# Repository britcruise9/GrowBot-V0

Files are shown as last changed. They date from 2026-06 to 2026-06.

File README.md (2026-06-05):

# GrowBot V0

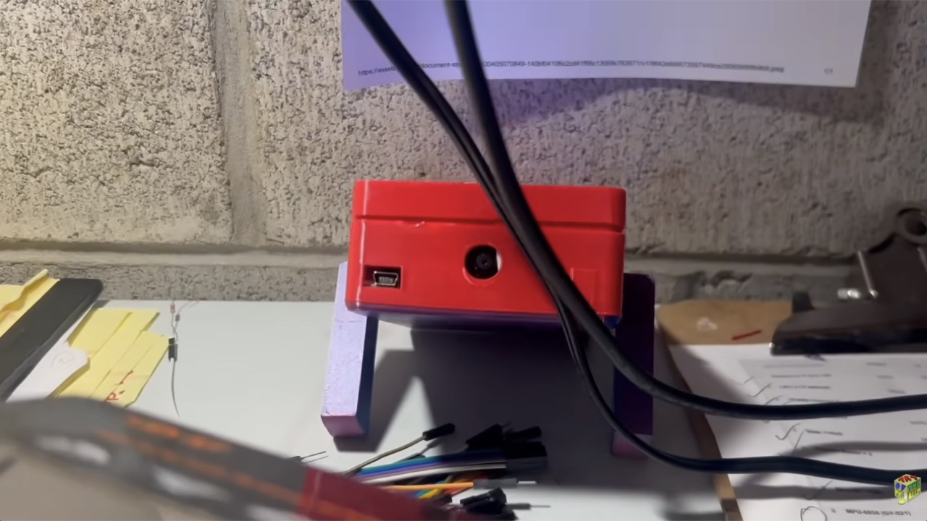
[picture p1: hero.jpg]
GrowBot V0 (https://www.youtube.com/watch?v=S67z2aekBrI)


▶ **[Watch the build video](https://www.youtube.com/watch?v=S67z2aekBrI)**

This project started when I imagined making a little robot that would learn everything, how to move and do things. A pure machine learning approach, using basic evolutionary algorithms and then a neural network. It then evolved to ask, "what if you gave a modern AI foundation model a nervous and motor system?" GrowBot collides these questions into a "general learning robot", which can be anything... and learns to move, see, and react from scratch.

Most importantly, getting physical AI in your hands: fast, easy, and cheap. So this project is the "simplest viable product": if you take a modern humanoid and delete everything down to the bare minimum, how cheap can you make it?

> [!WARNING]
> This is a V0 snapshot for research purposes, and it is still hacky (the servos and the Pi share a power rail, protected by a capacitor) because it is a work in progress. It is a reference for the build in the video, not a step by step guide for beginners, so expect to fill in some gaps. V1 is coming Fall 2026 as a more stable, tested platform with step by step build, testing, and training instructions, a custom PCBA, a calibrated digital twin, and a top secret thing I can't even show yet.

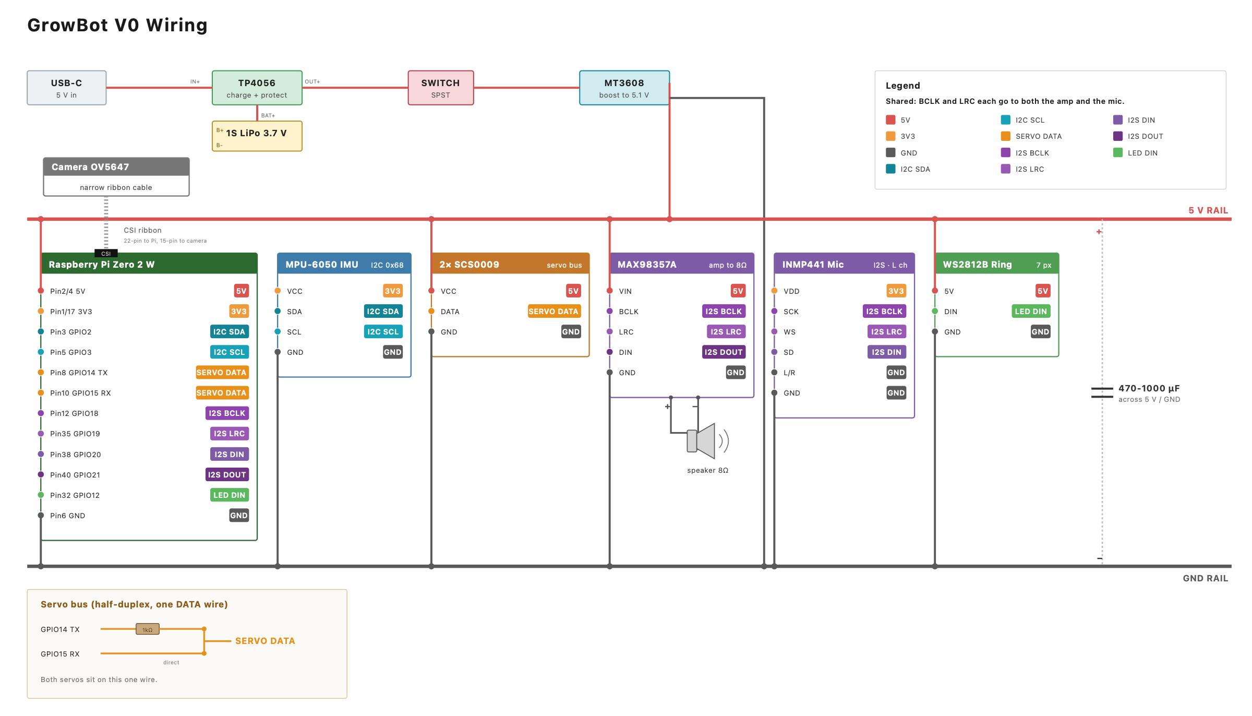
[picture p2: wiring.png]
GrowBot wiring diagram


## What's in here
- **[BOM.md](BOM.md)** is the full parts list with specs, rough prices, where I got things, the GPIO pin map, and the setup notes that gave me trouble.
- **[wiring.svg](wiring.svg)** is the full wiring diagram. The image above is the same thing.
- **[mechanical/stl_snapshot](mechanical/stl_snapshot)** is the current V0 body STL snapshot: holey top shell, matching base, and short rounded legs.
- **[simulation](simulation)** has a standalone MuJoCo body XML snapshot. The training setup is not included.

## The build at a glance
| Part of the robot | What I used |
|---|---|
| Brain | Raspberry Pi Zero 2 W (quad core, WiFi) and a microSD card |
| Legs | 2x Feetech SCS0009 serial bus servos (they report position and load) |
| Senses | OV5647 camera, MPU-6050 IMU, INMP441 mic |
| Voice and lights | MAX98357A amp into a small speaker, WS2812B LED ring |
| Power | one 1S LiPo into an MT3608 boost to 5 V, with a capacitor on the 5 V rail |

Everything runs on the Pi. There is no external computer.

## Software

Test policies are coming next, rolled out gradually as I verify each one on the robot.

The complete software is still in development. To get the hardware up and running, start with the basic setup and calibration software in **[`setup/`](setup/)**. Here is the big picture of what the hardware is built to support.

### LLM Integration (V0)
An onboard agent loop is the brain. It gathers the live sensor picture (camera, IMU, mic, servo feedback) and sends it to an LLM through an API. The model picks a goal and proposes an action, the robot tries it, and the result feeds back in. The WIP experimental runtime explores letting the LLM call the learned motor policies and sketch its own motions, with fast reflexes underneath as a safety floor.

### Learned Locomotion Policies
The low level motion comes from small motor policies that output bounded servo targets, not a hand written gait. I train them offline from short rollouts, then deploy compact versions onto the Pi. The robot logs its episodes, failures, and sensor traces so each run feeds the next training pass.

The training code, agent harness, reward functions, and trained policies are still under active development.

## License
[CC BY-NC 4.0](LICENSE): build it, modify it, and share it for non-commercial use, with credit to Art of the Problem.

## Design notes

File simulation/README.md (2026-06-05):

# GrowBot V0 Simulation Snapshot

`growbot_current_body.xml` is a standalone MuJoCo body snapshot for the current live GrowBot body.

The full setup is coming with the next version. For now it captures the measured body proportions and the rounded/rockered foot approximation I use for policy experiments. The agent harness, policy runtime, reward functions, and training code come with it.

The geometry is a measured box approximation of the same body the `mechanical/` STLs print
(body about 132 x 83 x 39 mm, 64 mm legs, the v215 rounded/rockered foot). It is close to the
printed shells within a few mm, not an exact mesh import, so print from the STLs and simulate
from this XML.

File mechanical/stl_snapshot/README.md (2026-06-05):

# GrowBot V0 STL Snapshot

This folder is a snapshot of the current V0 body geometry, shared as reference STL files. This is a work in progress and evolving at the moment, so expect the fit to keep changing.

| File | Notes |
|---|---|
| `growbot_v0_top_shell_holey.stl` | Top lid, fully perforated with vent holes, no text. Caps over the base. |
| `growbot_v0_base_shell.stl` | Base tray with corner mounting posts and side ports. Same footprint as the lid, so the top seats flush. |
| `growbot_v0_legs_64mm_rounded.stl` | Short 64 mm leg with a curved (rounded) foot. |

The body went through several revisions while I was building, so the holes and cutouts might not line up perfectly with the boards. The two holes in the middle of the body are for the IMU. I mounted things with 3M double sided squares instead of screws, which made small mismatches easy to work around.

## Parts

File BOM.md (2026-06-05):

# GrowBot V0 Bill of Materials

This is everything on the robot in the video. It is the single cell, breadboard friendly build, not the V1 PCB (that is a separate board I am still working on). If you want to copy what is in the video, this is the list.

The whole thing comes in well under $100.

## Parts

| # | Part | Spec | Qty | ~CAD | Where / notes |
|---|---|---|----:|----:|---|
| **Compute** |
| 1 | Raspberry Pi Zero 2 W | quad core A53, WiFi/BT, 40 pin | 1 | $22 | you will need to solder on a 40 pin header |
| 2 | microSD card | 16 to 32 GB, Class 10 / A1 | 1 | $8 | I run Raspberry Pi OS Lite (64 bit) |
| 3 | 2x20 GPIO header | 0.1 inch male | 1 | $1 | skip if your Pi already has one |
| **Actuation** |
| 4 | Feetech SCS0009 serial servo | half duplex UART 1 Mbps, 9 g, 1.5 kg·cm, 4 to 6 V (run ~5.1 V), 300° (same as Waveshare SC09) | 2 | $5 to 6 ea | I bought mine in bulk on AliExpress |
| 5 | 1 kΩ resistor | ¼ W | 1 | pennies | for the servo half duplex line |
| **Sensing** |
| 6 | MPU-6050 IMU (GY-521) | I²C 0x68, 6 axis, 3.3 V | 1 | $3 | |
| 7 | OV5647 camera (Pi Zero) | 5 MP, narrow 22 to 15 pin CSI ribbon | 1 | $12 | get the Pi Zero version with the narrow ribbon, not the standard one |
| 8 | INMP441 I²S mic | 3.3 V, 24 bit | 1 | $4 | |
| **Voice and lights** |
| 9 | MAX98357A I²S amp | 3.2 W class D mono | 1 | $5 | |
| 10 | speaker | 8 Ω, 0.5 to 3 W, small | 1 | $2 | |
| 11 | WS2812B LED ring | 7 pixels, 5 V | 1 | $3 | |
| **Power** |
| 12 | 1S LiPo or 18650 cell | 3.7 V, 800 to 1200 mAh | 1 | $4 | whatever you have on hand |
| 13 | TP4056 module | USB-C, charge and protect | 1 | $1 | get the protected version with OUT+/OUT- |
| 14 | MT3608 boost module | step up, set to about 5.1 V | 1 | pennies | |
| 15 | electrolytic cap | 470 to 1000 µF, 10 V or higher | 1 | pennies | goes across the 5 V rail at the servos |
| 16 | SPST power switch | | 1 | pennies | |
| | | | | **~$77 CAD** | about $56 USD |

## Also needed (not electronics)

- **3D printed body.** The STLs are in [`mechanical/`](mechanical/stl_snapshot/). Print in PLA or PETG, a small amount, well under a spool.
- **Hookup wire and dupont jumpers** to wire it up per the diagram.
- **Mounting.** I skipped screws and just stuck the boards down with 3M double sided mounting squares. Fast, and easy to move things around.

## GPIO pin map (Pi Zero 2 W, 40 pin header)

| Pi pin | Signal | Goes to |
|---:|---|---|
| 2 / 4 | 5 V | 5 V rail from the MT3608 (Pi, servos, amp, LED) |
| 1 | 3.3 V | IMU VCC |
| 17 | 3.3 V | mic VDD |
| 6 / 9 / 14 / 25 | GND | common ground rail |
| 3 | GPIO2 / SDA | IMU SDA |
| 5 | GPIO3 / SCL | IMU SCL |
| 8 | GPIO14 / TXD | 1 kΩ, then the servo DATA bus |
| 10 | GPIO15 / RXD | servo DATA bus (direct) |
| 12 | GPIO18 | amp BCLK and mic SCK (shared) |
| 35 | GPIO19 | amp LRC and mic WS (shared) |
| 38 | GPIO20 | mic SD (data in) |
| 40 | GPIO21 | amp DIN (data out) |
| 32 | GPIO12 | WS2812 DIN |
| CSI | ribbon | camera (not GPIO) |

## Power

> [!CAUTION]
> V0 runs the servos and the Pi off one shared 5 V rail. A capacitor across the rail covers the voltage dips when the servos pull hard. This is the hacky part of V0; V1 separates them properly.

The 3.3 V for the IMU and the mic comes from the Pi's own 3.3 V pins, not from the booster.

## Setup notes (the stuff that gave me trouble)

1. Set the MT3608 to about 5.1 V with a multimeter before you connect the Pi. These boost modules ship turned up high.
2. The servos talk over the Pi's serial port, but the Pi uses it for other things by default. To hand it to the servos: add `dtoverlay=disable-bt` to `/boot/config.txt` (this frees the good serial port from Bluetooth), and in `raspi-config` turn the serial login off but leave the serial port itself on. After that the servos are on `/dev/serial0`.
3. The SCS0009 use big endian byte order for the 2 byte reads and writes. I assumed little endian at first and it silently read and wrote garbage.
4. Assign servo IDs 1 and 2 (both ship as ID 1, so you need to change one). This was a headache at first. The 3-pin servo lead is GND, VCC (5 V), DATA, but check your own servo's pinout before plugging in.
5. Torque limit the servos to about 70 percent so a double stall stays inside the MT3608's 2 A budget, otherwise use dedicated power for full load (a second MT3608 on the same ground).
6. Mic L/R to GND gives the left channel. The amp SD pin has to be high to play sound, so tie it to 3.3 V, and leaving the amp GAIN pin floating is about 9 dB.
7. The Pi Zero needs the narrow CSI ribbon (22 pin to 15 pin), not the standard camera ribbon.
8. The WS2812 data line needs root, so launch with `sudo`.

## Power budget

| Draw | Typical | Peak |
|---|---:|-----:|
| Pi Zero 2 W | 200 mA | 400 mA |
| 2x SCS0009 (walking) | 400 mA | 1700 mA (both stalling) |
| Audio and LEDs | ~100 mA | ~400 mA |
| **Total** | **~700 mA** | **~2.1 A** |

The MT3608 is rated around 2 A, so normal walking is fine. A double stall goes over budget, which is why I torque limit the servos and added a capacitor to cover the dips.

Battery life is roughly 50 to 60 minutes of active play on an 800 to 1200 mAh cell.

## Software

The setup and calibration software is in [`setup/`](setup/). The learning agent and training code are still in development (V1).

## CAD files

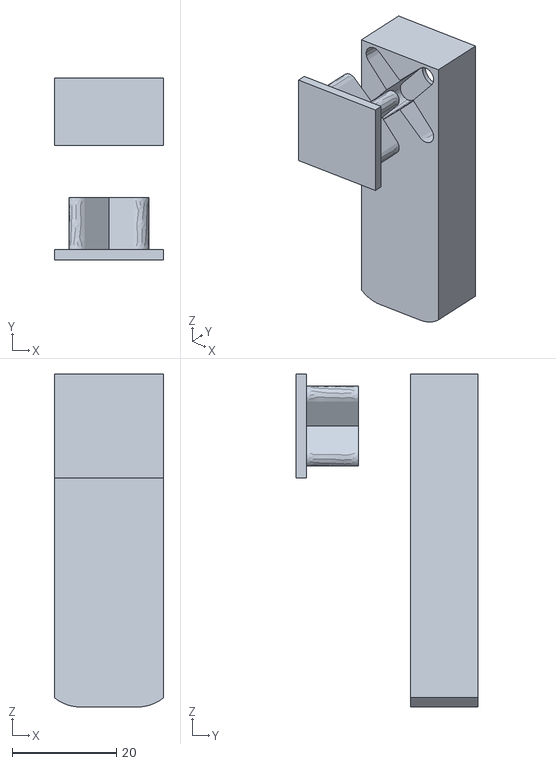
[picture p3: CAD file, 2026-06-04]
mechanical/stl_snapshot/growbot_v0_legs_64mm_rounded.stl
21.0 x 35.0 x 64.0

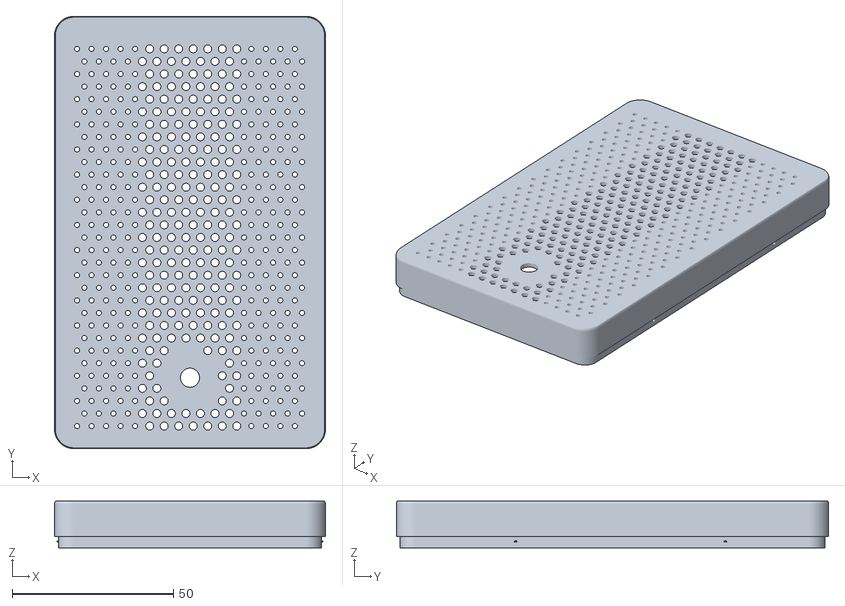
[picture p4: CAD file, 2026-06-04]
mechanical/stl_snapshot/growbot_v0_top_shell_holey.stl
84.0 x 134.0 x 14.5

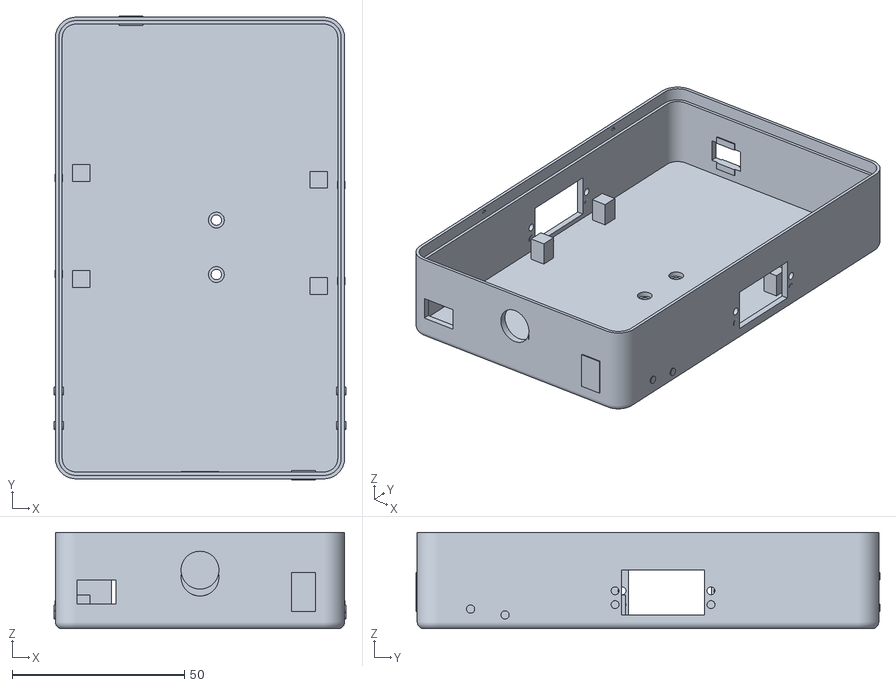
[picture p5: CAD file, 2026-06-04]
mechanical/stl_snapshot/growbot_v0_base_shell.stl
84.7 x 134.7 x 28.0

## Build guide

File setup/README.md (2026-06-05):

# GrowBot V0 Setup and Calibration Software

This is the basic software to bring the GrowBot hardware to life. It is a small driver package plus one quick test per subsystem (servos, LED ring, speaker, mic, IMU, camera), and a `hello_growbot.py` that runs lights, voice, and legs together. Its job is to prove the body works. It does not include the learning agent, the LLM brain, or the training code. Those are V1, still in development.

> [!IMPORTANT]
> The SCS0009 / SC09 servos store 2-byte values big-endian, for reads and writes. If you get nonsense positions or a servo that will not move past some point, check the byte order first. Little-endian code (Dynamixel style) looks like it works, then silently writes garbage. That one fact cost me a full day, so the driver here gets it right.

## What's in it

Drivers in `growbot/` (you import these):

| Module | What it does |
|---|---|
| `pins.py` | every wiring constant in one place (port, servo IDs, GPIO pins, encoder range). **Edit this to match your build.** |
| `servos.py` | SCS0009 servos, big-endian correct: scan, read position, move, sync-move |
| `leds.py` | WS2812 ring on GPIO12: fill, spin, off |
| `audio.py` | `speak(text)` through espeak-ng/flite and aplay; sample the mic level |
| `imu.py` | MPU-6050 over I2C: WHO_AM_I, accel, gyro |
| `camera.py` | capture one still from the Pi camera |

Scripts in `scripts/` (you run these):

| Command | What it does |
|---|---|
| `python3 scripts/scan_servos.py` | read-only: finds servos, prints positions, no motion |
| `python3 scripts/test_servos_safe.py` | nudges each leg a few degrees and back, then goes limp |
| `sudo python3 scripts/test_leds.py` | ring through red, green, blue, white, then a spin |
| `python3 scripts/test_audio.py` | says "hello, I'm GrowBot", then samples the mic |
| `python3 scripts/test_imu.py` | prints WHO_AM_I and live accel/gyro, tilt it to watch |
| `python3 scripts/test_camera.py` | captures one photo to /tmp |
| `sudo -E python3 scripts/hello_growbot.py` | the full hello: lights, voice, legs. Skips whatever is not present. |

## Setup

```bash
pip install -r requirements.txt
sudo apt install espeak-ng   # text-to-speech (flite also works)
# picamera2 and alsa-utils (aplay/arecord) ship with Raspberry Pi OS
```

The LED ring uses the Pi's PWM/DMA for WS2812 timing, which needs root, so run the LED test and the full hello with `sudo`.

## Quickstart

```bash
python3 scripts/scan_servos.py            # confirm the servo bus (read-only)
python3 scripts/test_servos_safe.py       # gentle leg nudge (hold the robot or use a stand)
sudo python3 scripts/test_leds.py         # ring colors and a spin
python3 scripts/test_audio.py             # speaker says hello, mic level
python3 scripts/test_imu.py               # tilt to watch accel/gyro
python3 scripts/test_camera.py            # one photo to /tmp
sudo -E python3 scripts/hello_growbot.py  # lights, voice, legs together
```

If `scan_servos.py` can't open the port: on a Pi Zero 2W the servo bus is `/dev/serial0` (the real PL011 UART), not `/dev/ttyS0` (which throws an Input/output error). Enable it with `raspi-config` > Interface Options > Serial Port: login shell off, serial hardware on, then reboot.

## SCS0009 register cheat sheet

All 2-byte values are big-endian.

| Reg | Name | Bytes | Notes |
|-----|---|---|---|
| 0x03 | ID | 1 | 1 to 253 |
| 0x28 | torque enable | 1 | 0 = limp, 1 = holding |
| 0x2A | goal position | 2 BE | 0 to 1023 |
| 0x30 | EEPROM lock | 1 | write 0 to unlock before changing 0x00 to 0x2F, 1 to lock |
| 0x38 | present position | 2 BE | read-only |

Packet: `FF FF <id> <len> <inst> <params...> <checksum>`, where `len = len(params) + 2` and `checksum = ~(id + len + inst + sum(params)) & 0xFF`. The bus is half-duplex, so every send is echoed back before the reply; strip the echo before parsing. The driver does this and checks the checksum so a stray echo byte can't be read as a position.

The SCS0009 reports 0 to 1023 across about 300 degrees. On my units the usable floor is 255, so the driver clamps motion to 255 to 1023.

## Tested on

A Raspberry Pi Zero 2W (Raspberry Pi OS Bookworm, 64-bit) with two SCS0009 servos on the PL011 UART at 1 Mbaud, an MPU-6050 IMU at I2C 0x68, a 7-pixel WS2812 ring on GPIO12, a MAX98357A amp into a speaker, an INMP441 mic, and a Pi camera. Your build will differ, so `growbot/pins.py` is where you reconcile it.

Audio note: the MAX98357A is usually set up with the googlevoicehat-soundcard overlay, so its ALSA card shows up as `sndrpigooglevoi` (that is the default in `pins.py`; change it if yours differs). If a play returns cleanly but you hear nothing, it is almost always speaker wiring, not software.

## Safety

These scripts move a real robot. `test_servos_safe.py` and `hello_growbot.py` move each joint a few degrees around where it currently is, so keep GrowBot on a stand or hold it, and keep fingers clear. Motion is clamped in software to the usable encoder range, and torque is released on exit, even on Ctrl-C. The scripts talk to servos by ID and make no left/right assumption, so you can bring up the bus before you have settled your own leg mapping.

## License

[CC BY-NC 4.0](../LICENSE), the same as the rest of the repo. Build it, change it, and share it for non-commercial use, with credit to Art of the Problem.

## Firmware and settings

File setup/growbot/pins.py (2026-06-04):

"""Bus, encoder, and register constants for the GrowBot bringup kit.

These describe how GrowBot's hardware is wired and its safe operating limits.
Edit them to match YOUR build.
"""

# --- Servo bus (SCS0009 / SC09 Feetech serial-bus servos) ---
# On a Raspberry Pi Zero 2W this is the real PL011 UART. NOT /dev/ttyS0, which
# exists but raises termios.error (5, 'Input/output error').
SERVO_PORT = "/dev/serial0"
SERVO_BAUD = 1_000_000

# Servo IDs present on the bus. GrowBot has two legs.
SERVO_IDS = (1, 2)

# Usable encoder range. The SCS0009 reports 0-1023 over its ~300 deg of travel,
# but the usable floor on our units is 255 - commanding below that just stalls
# at 255. Motion is clamped to this range so you can't drive into the dead zone.
ENCODER_MIN = 255
ENCODER_MAX = 1023

# Conservative nudge size (encoder units) for the safe-motion smoke tests.
# ~30 units is a few degrees: visible, gentle, nowhere near the end stops.
SAFE_NUDGE = 30

# --- SCS0009 register map (all 2-byte values are BIG-ENDIAN) ---
REG_ID = 0x03             # 1 byte, 1-253 (changing IDs is intentionally not in V0)
REG_TORQUE_ENABLE = 0x28  # 1 byte: 0 = off (limp), 1 = on (holding)
REG_GOAL_POS = 0x2A       # 2 bytes BE, 0-1023
REG_EEPROM_LOCK = 0x30    # 1 byte: write 0 to unlock, 1 to lock
REG_PRESENT_POS = 0x38    # 2 bytes BE, read-only

# --- IMU (MPU-6050 family) over I2C ---
IMU_I2C_ADDR = 0x68

# --- LED ring (WS2812 / NeoPixel) - needs root (PWM/DMA) ---
LED_PIN = 12          # GPIO12 = PWM0
LED_COUNT = 7
LED_BRIGHTNESS = 128  # 0-255
LED_FREQ_HZ = 800_000
LED_DMA = 10
LED_CHANNEL = 0       # PWM0 -> channel 0 (GPIO12/18); use 1 for GPIO13/19

# --- Audio (MAX98357A amp + INMP441 mic) ---
# ALSA device. The MAX98357A is usually set up with the googlevoicehat-soundcard
# overlay, so the card shows up as 'sndrpigooglevoi'. If yours differs, change this;
# audio.py also falls back to the default device if this one is not found.
AUDIO_DEVICE = "plughw:CARD=sndrpigooglevoi"
HELLO_PHRASE = "hello, I'm GrowBot"

# --- Body mapping ---
# NOTE: which servo ID drives which leg depends on YOUR horn mounting, so this
# kit never assumes a side - it tests servos by ID and nudges around each
# joint's current position. Record your own mapping here once you've confirmed
# it, e.g. LEFT_LEG_ID = 2 / RIGHT_LEG_ID = 1.

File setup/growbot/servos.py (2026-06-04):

"""Minimal big-endian-correct driver for SCS0009 / SC09 serial-bus servos.

The one fact that costs everyone a day: the SCS0009 stores 2-byte values
BIG-ENDIAN, for BOTH reads and writes. Dynamixel-style little-endian code
appears to work but silently writes garbage that the servo clips to its max
angle - which looks like a servo that refuses to move past some point.

Tested against SCS0009 servos on a Raspberry Pi Zero 2W over the raw UART
(no vendor SDK). Run scripts/scan_servos.py first to confirm the bus before
commanding any motion.
"""
from __future__ import annotations

import time

try:
    import serial  # pyserial
except ImportError:  # pragma: no cover - dependency hint
    serial = None

from .pins import (
    ENCODER_MAX,
    ENCODER_MIN,
    REG_GOAL_POS,
    REG_PRESENT_POS,
    REG_TORQUE_ENABLE,
    SERVO_BAUD,
    SERVO_PORT,
)

# Instruction codes
PING = 0x01
READ = 0x02
WRITE = 0x03
SYNC_WRITE = 0x83
BROADCAST_ID = 0xFE


def _checksum(sid: int, length: int, inst: int, params: list[int]) -> int:
    return (~(sid + length + inst + sum(params))) & 0xFF


def _packet(sid: int, inst: int, params: list[int]) -> bytes:
    length = len(params) + 2
    return bytes([0xFF, 0xFF, sid, length, inst] + list(params) + [_checksum(sid, length, inst, params)])


def _find_response(buf: bytes, sid: int) -> bytes | None:
    """Locate a checksum-valid response packet for ``sid`` inside ``buf``.

    Robust to the half-duplex echo and UART timing jitter: it scans for a
    well-formed ``FF FF <sid> ...`` frame whose checksum validates, rather than
    trusting byte offsets.
    """
    i = 0
    while i < len(buf) - 5:
        if buf[i] == 0xFF and buf[i + 1] == 0xFF and buf[i + 2] == sid:
            ln = buf[i + 3]
            end = i + 4 + ln
            if end <= len(buf):
                body = buf[i + 2 : end]
                if body[-1] == ((~sum(body[:-1])) & 0xFF):
                    return buf[i:end]
        i += 1
    return None


class ServoBus:
    """A thin, big-endian-correct interface to the SCS0009 servo bus."""

    def __init__(self, port: str = SERVO_PORT, baud: int = SERVO_BAUD, timeout: float = 0.05) -> None:
        if serial is None:
            raise RuntimeError("pyserial is not installed - run: pip install pyserial")
        self.ser = serial.Serial(port, baud, timeout=timeout)

    def close(self) -> None:
        try:
            self.ser.close()
        except Exception:
            pass

    def __enter__(self) -> "ServoBus":
        return self

    def __exit__(self, *exc) -> None:
        self.close()

    # --- low level -------------------------------------------------------
    def _txrx(self, sid: int, inst: int, params: list[int], read_extra: int = 16) -> bytes | None:
        pkt = _packet(sid, inst, params)
        self.ser.reset_input_buffer()
        self.ser.write(pkt)
        self.ser.flush()
        time.sleep(0.004)
        buf = self.ser.read(len(pkt) + read_extra)
        # Search after the TX echo so the echoed packet isn't read as a reply.
        idx = buf.find(pkt)
        start = idx + len(pkt) if idx >= 0 else 0
        return _find_response(buf[start:], sid)

    def ping(self, sid: int) -> bool:
        return self._txrx(sid, PING, [], read_extra=6) is not None

    def read_bytes(self, sid: int, reg: int, size: int) -> list[int] | None:
        resp = self._txrx(sid, READ, [reg, size], read_extra=size + 6)
        if not resp or len(resp) < 5 + size:
            return None
        return list(resp[5 : 5 + size])

    def read_word(self, sid: int, reg: int) -> int | None:
        data = self.read_bytes(sid, reg, 2)
        if not data:
            return None
        return (data[0] << 8) | data[1]  # BIG-ENDIAN

    def read_byte(self, sid: int, reg: int) -> int | None:
        data = self.read_bytes(sid, reg, 1)
        return data[0] if data else None

    def write_bytes(self, sid: int, reg: int, data: list[int]) -> None:
        self._txrx(sid, WRITE, [reg] + list(data), read_extra=6)

    def write_word(self, sid: int, reg: int, val: int) -> None:
        val = int(val) & 0xFFFF
        self.write_bytes(sid, reg, [(val >> 8) & 0xFF, val & 0xFF])  # BIG-ENDIAN

    def write_byte(self, sid: int, reg: int, val: int) -> None:
        self.write_bytes(sid, reg, [int(val) & 0xFF])

    # --- semantic helpers ------------------------------------------------
    def present_position(self, sid: int) -> int | None:
        """Read the servo's current encoder position (0-1023), or None."""
        return self.read_word(sid, REG_PRESENT_POS)

    def set_torque(self, sid: int, on: bool) -> None:
        """Enable (hold) or disable (go limp) the servo's torque."""
        self.write_byte(sid, REG_TORQUE_ENABLE, 1 if on else 0)

    def move(self, sid: int, pos: int) -> int:
        """Command a single servo to an encoder position, clamped to the safe range."""
        pos = max(ENCODER_MIN, min(ENCODER_MAX, int(pos)))
        self.write_word(sid, REG_GOAL_POS, pos)
        return pos

    def move_sync(self, targets: dict[int, int]) -> None:
        """Command several servos at once (true simultaneous motion).

        Sequential single-servo writes let one joint finish before the next
        starts; sync-write (instruction 0x83, broadcast ID) moves them together.
        """
        params: list[int] = [REG_GOAL_POS, 2]
        for sid, pos in targets.items():
            pos = max(ENCODER_MIN, min(ENCODER_MAX, int(pos)))
            params += [sid, (pos >> 8) & 0xFF, pos & 0xFF]
        length = len(params) + 2
        csum = (~(BROADCAST_ID + length + SYNC_WRITE + sum(params))) & 0xFF
        self.ser.write(bytes([0xFF, 0xFF, BROADCAST_ID, length, SYNC_WRITE] + params + [csum]))
        self.ser.flush()
        self.ser.reset_input_buffer()

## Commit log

2026-06-04 GrowBot V0: parts list, wiring diagram, and build notes
2026-06-04 Add V0 mechanical and simulation snapshots
    [growbot_v0_base_shell.stl, growbot_v0_legs_64mm_rounded.stl, growbot_v0_top_shell_holey.stl]
2026-06-04 Add V0 setup and calibration software (drivers, tests, README)
2026-06-04 Correct sim body: leg thickness 13.5mm, horn height 54mm (measured)
2026-06-05 BOM: add non-electronic materials (filament, wire, mounting); note body revisions/fit
2026-06-05 BOM: software section now points to setup/ (it shipped)
2026-06-05 Mechanical README: WIP note up top, note IMU holes
2026-06-05 Review fixes: servo 4-6V spec, soften software claims, split setup intro
